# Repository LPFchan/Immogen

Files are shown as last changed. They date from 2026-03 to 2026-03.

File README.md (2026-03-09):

# Immogen — Ninebot G30 BLE Immobilizer

**Immogen** is a three-part BLE immobilizer system for the Ninebot Max G30, consisting of **[Uguisu](https://github.com/LPFchan/Immogen/tree/main/Uguisu#readme)** (key fob), **[Guillemot](https://github.com/LPFchan/Immogen/tree/main/Guillemot#readme)** (deck receiver), and **[Whimbrel](https://github.com/LPFchan/Whimbrel)** (Web Serial provisioning app).

Guillemot sits inline between the battery and ESC via an XT60 splice. Without a valid BLE unlock from Uguisu, the scooter stays inoperable. Male/female pigtails keep the install reversible—no permanent modification required.

```
┌─────────────────┐       BLE advertisement        ┌──────────────────────┐
│  UGUISU (FOB)   │ ─────────────────────────────> │ GUILLEMOT (RECEIVER) │
│  XIAO nRF52840  │       (2.4 GHz, ~2 m)          │  XIAO nRF52840       │
└───────┬─────────┘                                └──────────┬───────────┘
        │                                                     │
        │                 ┌────────────────────┐              │
        └──────(USB-C)──> │ WHIMBREL (WEB APP) │ <──(USB-C)───┘
       (Provisioning)     │ Chrome / Edge      │    (Provisioning)
                          └────────────────────┘
```

## Repository Structure

| Path | Description |
| --- | --- |
| `Uguisu/` | Key fob — firmware, KiCad, BOM. Button press → 2 s BLE broadcast → sleep. [README](https://github.com/LPFchan/Immogen/tree/main/Uguisu#readme) |
| `Guillemot/` | Deck receiver — firmware, KiCad, BOM. Duty-cycled scan (5%), validates adverts → SR latch → power gate. [README](https://github.com/LPFchan/Immogen/tree/main/Guillemot#readme) |
| `lib/` | Shared C++ library: AES-128-CCM MIC, provisioning loop, LittleFS counter storage |
| `tools/` | LED visualizer, BLE timing simulator, buzzer tuner (HTML); MIC test vectors (`gen_mic.py`) |
| `logs/` | Migration reports and guides |

## BLE Protocol

Advertisement-only; no persistent connection. Both devices share a company ID and pre-shared key (PSK). Each advertisement carries a 13-byte payload after the 2-byte company ID:

| Offset | Size | Field | Purpose |
| --- | ---- | --- | --- |
| 0 | 4 | counter | Anti-replay, monotonic |
| 4 | 1 | command | 0x01 = Unlock, 0x02 = Lock |
| 5 | 8 | mic | AES-128-CCM auth tag |

For full protocol details see the [Guillemot](https://github.com/LPFchan/Immogen/tree/main/Guillemot#readme) and [Uguisu](https://github.com/LPFchan/Immogen/tree/main/Uguisu#readme) READMEs.

## Quick Start

Pre-built firmware is available on the [Releases](https://github.com/LPFchan/Immogen/releases) page. Use [Whimbrel](https://github.com/LPFchan/Whimbrel) to flash and provision keys via Web Serial.

**Build from source:**

```bash
# Deck receiver
cd Guillemot/firmware && pio run

# Key fob
cd Uguisu/firmware && pio run
```

## Roadmap

- Uguisu enclosure CAD (3D print).
- First-build validation: PPK2 power, BLE range through deck, pre-charge waveform.

## Safety & Legal

- Prototype security/power-interrupt device. Use at your own risk.
- Not affiliated with Segway-Ninebot.
- **Do not test lock behavior while riding.**

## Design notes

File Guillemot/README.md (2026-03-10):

# Guillemot — Ninebot G30 BLE Immobilizer Receiver

Guillemot is the deck receiver in a three-part immobilizer system ([Uguisu](https://github.com/LPFchan/Immogen/tree/main/Uguisu) fob + [Whimbrel](https://github.com/LPFchan/Whimbrel) web app) for the Ninebot Max G30. It validates encrypted BLE advertisements from the fob and controls an SR latch that gates battery-to-ESC power via an inline XT60 splice. Male/female pigtails make it fully reversible—no permanent modification to the vehicle. Protocol and cryptography are handled by the shared [lib/](https://github.com/LPFchan/Immogen/tree/main/lib) in this monorepo ([Immogen](https://github.com/LPFchan/Immogen)).

---

## Hardware

### Placement

Mount Guillemot on the plastic underside of the deck for good 2.4 GHz RF.

### Components & BOM (~$20)

| Ref | Part | Notes | JLCPCB # | Cost |
| --- | --- | --- | --- | --- |
| U1 | XIAO nRF52840 | MCU: BLE scanning, latch control, buzzer PWM | Seeed | $8.23  |
| U2 | SN74LVC2G02DCTR | SR latch: Q = unlock. 10 nF + 100 kΩ differentiator for POR pulse | C94600 (ext.) | $0.53  |
| PS1 | TPSM365R6V3RDNR | Buck: 3–65 V in, 3.3 V/600 mA, 4 μA Iq. Feeds XIAO 3V3 directly.  | C18208843 (ext.) | $3.59  |
| Q1 | IPB042N10N3G | Main MOSFET: 100 V/137 A, D2PAK, low-side GND return | C69300 (ext.) | $0.75  |
| Q2 | AO3422 | Pre-charge FET, inrush ~0.8 A. Driven by latch Q. | C37130 (ext.) | $0.23  |
| Q3 | SI2309CDS | Bleeder P-FET: disconnects 10 kΩ bleeder when locked (0 μA) | C10493 (ext.) | $0.23  |
| Q4 | 2N7002 | Gate drive | C8545 | $0.01  |
| Q5, Q6 | MMBT3904 | Buzzer driver | C20526 | $0.02  |
| BZ1 | FUET-1230 | Buzzer: 12×12×3 mm SMD, 4 kHz. Driven by MMBT3904 | C391037 (ext.) | $0.47  |
| D1 | BZT52C12-7-F | 12 V Zener | C124196 (ext.) | $0.11  |
| D2 | BZT52C10-7-F | 10 V Zener | C155227 (ext.) | $0.10  |
| D3, D4 | 1N4148W | Gate isolation from buzzer rail sag | C81598 | $0.01  |
| D5 | SMBJ45A | 45 V TVS diode for transient suppression | C114005 (ext.) | $0.08  |
| C1 | 10 nF (0603) | POR pulse differentiator | C57112 | $0.003 |
| C2 | 100 µF (1210) | Bulk decoupling. EMK325ABJ107MM-P 16V X5R ±20% | C90143 (ext.) | $0.31  |
| C3, C4 | 1 µF (0603) | RC delay bypass, gate isolation | C15849 | $0.01  |
| R1, R2 | 100 kΩ (0603) | Latch input pull-downs (prevent floating during WDT reset) | C25803 | $0.006 |
| R3, R7 | 100 kΩ (0603) | Gate drive, RC delay (τ = 100 ms) | C25803 | $0.006 |
| R4 | 1 MΩ (0603) | P-FET gate pull-up | C22935 | $0.001 |
| R5 | 10 kΩ (0603) | Bleeder resistor | C25804 | $0.001 |
| R6 | 4.7 kΩ (0603) | Piezo buzzer discharge resistor | C23162 | $0.001 |
| R8 | 47 Ω 2 W (2512) | Pre-charge resistor, inrush ~0.77–0.89 A | C136992 (ext.) | $0.10  |
| TP1–5 | XT60 + 12 AWG | Pigtails and GND jumper | Generic | — |
| — | PCB | 54×34 mm, 2 oz outer | JLCPCB | $1.60  |

JLCPCB P&P for SMT. Hand-solder XIAO edges, XT60 pigtails, and the GND jumper.

### PCB Layout

4-layer, 54×34 mm, 2 oz outer copper, designed for 30 A continuous.

- **12 AWG GND jumper (critical):** Main battery return bypasses inner layers. Run an external silicone wire from the `BAT-` XT60 pad to the MOSFET source pad.
- **Power traces:** `+BATT` and `ESC-` as top-layer pours. No high-current vias.
- **Clearance:** ≥ 0.6 mm between 42 V power and 3.3 V logic.
- **Pre-charge trace:** Q2 → R8 → `ESC-` routed at **1.0 mm** to survive initial ~40 W inrush surge.
- **RF keepout:** Strip copper on all layers under the XIAO's BLE antenna trace.
- **Assembly:** Single-sided (F.Cu) SMT for easy JLCPCB PCBA.

### Operation

- **Unlock flow:** Uguisu advert → MCU validates → SET latch → Q HIGH → pre-charge 100 ms → MOSFET ON → buzzer tone.
- **Lock flow:** Uguisu advert → MCU validates → buzzer tone → RESET latch → Q LOW → P-FET OFF, pre-charge OFF → MOSFET OFF.
- **Power (locked):** ~306 μA (buck Iq + 5% duty-cycled scan + latch). At 306 μA, a G30 (15.3 Ah) would theoretically take ~5.7 years to drain; battery self-discharge (~12 months) dominates in practice. See `logs/15-BLE_POWER_ANALYSIS_AND_DOCUMENTATION_DISCREPANCY.md` for derivation.
- **Buzzer timing:** Unlock tone ~34 ms after 10 V rail up; lock tone before RESET.

### Design Notes

- **EasyEDA → KiCad:** Schematics and PCBs are designed in KiCad. [easyeda2kicad](https://github.com/wokwi/easyeda2kicad) is used to import symbols and footprints from EasyEDA/LCSC. Example: `easyeda2kicad --full --lcsc_id=Cxxxx` (replace `Cxxxx` with the LCSC part number).
- **Latch Input Pull-downs (100 kΩ):** R1 and R2 hold `MCU_D0` (SET) and `MCU_D1` (RESET) strictly LOW. This is critical because the nRF52840's pins float (high-impedance) during the 8-second hardware Watchdog Timer (WDT) reset cycle. Without these resistors, noise or capacitive coupling could randomly toggle the latch and power state while the MCU reboots.
- **AO3422:** 55 V Vds provides margin over the 42 V bus when locked.
- **Gate drive R (100 kΩ):** Protects the 2N7002 and BZT Zeners.
- **POR circuit (10 nF + 100 kΩ):** 1 ms RC differentiator—brief pulse zeros the latch at power-on.
- **RC delay (100 kΩ + 1 μF):** 1N4148W bypass for fast turn-off.
- **Gate isolation (1N4148W + cap):** Buzzer draw exceeds bleeder supply; diode and 1 μF hold cap prevent gate sag during tones (Vgs ≈ 9.3 V).
- **Gate pull-down (MMBT3904):** Via Q̄/RC, discharges hold cap for instant OFF.
- **IPB042N10N3G:** Outperforms TO-220 standing upright in sealed deck enclosures when thermal pad is stitched to B.Cu. **IPB035N10NF2S (3.5 mΩ)** is the long-term successor depending on LCSC stock.

---

## Software

### Firmware

[PlatformIO](https://platformio.org/) project in `firmware/`

Scanning is duty-cycled (25 ms every 500 ms, 5% duty) for reliable detection. P(detect) = 100% per button press because `scanWindow (25 ms) ≥ advInterval (20 ms)` guarantees full phase coverage. The receiver rejects any payload with an invalid AES-CCM MIC or a counter less than or equal to the last seen value (anti-replay). The receiver is also protected against MCU hangs by an 8-second hardware Watchdog Timer (WDT) which triggers a clean reboot without disrupting the latch state.

### Protocol

Validation and crypto via shared [lib/](https://github.com/LPFchan/Immogen/tree/main/lib). See [Immogen README § BLE Protocol](https://github.com/LPFchan/Immogen#ble-protocol) for full specification.

### Onboarding

Use [Whimbrel](https://github.com/LPFchan/Whimbrel) for both tasks:

- **Firmware flashing:** Web-based flasher via Web Serial. Enter bootloader mode with a double-tap on reset.
- **Key provisioning:** Connect via USB; Whimbrel injects the shared AES-128 key. Physical presence is required. The firmware has no serial commands to read the key back.

---

## Safety & Notes

- Prototype security and power-interrupt device. Use at your own risk.
- Do not test lock behavior while riding.
- Not affiliated with Segway-Ninebot.
- Avoid committing KiCad per-user state (`*.kicad_prl`) or lock files.

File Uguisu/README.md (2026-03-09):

# Uguisu — Ninebot G30 BLE Immobilizer Fob

Uguisu is the BLE key fob in a three-part immobilizer system ([Guillemot](https://github.com/LPFchan/Immogen/tree/main/Guillemot) receiver + [Whimbrel](https://github.com/LPFchan/Whimbrel) web app) for the Ninebot Max G30. It broadcasts short, encrypted BLE advertisements on button press to unlock or lock the vehicle. This repository contains the fob firmware and hardware design files. Protocol and cryptography via the shared [lib/](https://github.com/LPFchan/Immogen/tree/main/lib) in this monorepo ([Immogen](https://github.com/LPFchan/Immogen)).

---

## Hardware

### Components & BOM (~$10)

| Ref | Part | Notes | Source / LCSC | Cost  |
| --- | --- | --- | --- | ----- |
| U1 | XIAO nRF52840 | Castellated, 21×17.5 mm | Seeed/Amazon  | $6.00 |
| BAT | TW-502535 | 3.7V 400mAh LiPo | Generic | $2.00 |
| KEY1 | SKQGABE010 | Tactile Switch SMD-4P 5.2x5.2mm | C115351 | $0.11 |
| LED1 | XL-5050RGBC | SMD5050-6P RGB LED Common Anode | C2843868 | $0.05 |
| R1, R3 | 120 Ω | 0603WAF1200T5E, 100mW 1% (Blue/Green) | C22787 | <$0.01|
| R2 | 330 Ω | 0603WAF3300T5E, 100mW 1% (Red) | C23138 | <$0.01|
| — | Enclosure | ~50×35×12 mm, 3D-printed | Homemade | — |

Hand-solder XIAO and LiPo.

### PCB Design

KiCad (`hardware/Uguisu.kicad_sch` / `hardware/Uguisu.kicad_pcb`).

### GPIO

| Function | Pin | nRF P0.x | Notes |
| --- | --- | --- | --- |
| Button (KEY1) | D0  | P0.02 | Active-low, internal pull-up, wake-from-system-off |
| Blue (LED1) | D1  | P0.03 | LED1 pin 1, R1 120 Ω, active-low (sink) |
| Red (LED1) | D2  | P0.28 | LED1 pin 2, R2 330 Ω, active-low (sink) |
| Green (LED1)  | D3  | P0.29 | LED1 pin 3, R3 120 Ω, active-low (sink) |

### RGB LED Behaviour

| Situation | Color  | Pattern |
| --- | --- | --- |
| Unlock | Green  | Single pulse (fade-in/hold/fade-out) |
| Lock | Red | Single pulse (fade-in/hold/fade-out) |
| Serial provisioning | Blue | Repeating pulse loop |
| Low battery + Unlock | Green  | Rapid pulse loop for 2 s |
| Low battery + Lock | Red | Rapid pulse loop for 2 s |
| Fatal error (FS fail)  | Red | Fast blink + onboard LED |

All timing constants live in `firmware/include/led_effects.h`. Use `tools/led_visualizer.html` (repo root; open in any browser) to preview and fine-tune durations before flashing.

### Operation

- **Unlock flow:** Short press (< 1 s) → green flash → BLE broadcast ~2 s → sleep.
- **Lock flow:** Long press (≥ 1 s) → red flash → BLE broadcast ~2 s → sleep.
- **Low battery:** Battery checked after button press; replaces single flash with 2 s pulse loop in the same color while advertising.
- **Power:** ~30 μA standby (nRF52840 system-off + XIAO charging IC), ~0.006 mAh per press (12–18 months between charges on 400 mAh LiPo). Charging via USB-C.

### Design Notes

- **EasyEDA → KiCad:** Schematics and PCBs are designed in KiCad. [easyeda2kicad](https://github.com/wokwi/easyeda2kicad) is used to import symbols and footprints from EasyEDA/LCSC. Example: `easyeda2kicad --full --lcsc_id=Cxxxx` (replace `Cxxxx` with the LCSC part number).
- **NVS wear:** Counter written every press (System OFF kills RAM). At 10 unlocks/day, ~2.7 years; wear-leveling extends this.

---

## Software

### Firmware

[PlatformIO](https://platformio.org/) project in `firmware/`.

**Boot flow:**

```
led::init()
g_store.begin()          — fail → error_loop() [red rapid blink + onboard LED, forever]
load_provisioning()

VBUS present?
  yes → prov_led_task (blue pulse, FreeRTOS)
        ensure_provisioned()   [waits for PROV: serial packet]
        stop prov_led_task
        led::off()

Bluefruit.begin() / setName / setTxPower

wait_for_button_press_release(10 s)
  timeout → system_off()

command = press ≥ 1 s ? Lock : Unlock
cmd_pin = Lock ? PIN_LED_R : PIN_LED_G
low_bat = readVbat_mv() < LED_LOWBAT_MV_THRESHOLD

[crypto: nonce → msg → AES-128-CCM MIC]
  fail → system_off()

g_store.update(counter)
start_advertising_once()     — BLE advertising starts
adv_start = millis()

low_bat?
  yes → flash_low_battery(cmd_pin)   [~2 s repeating pulses, same color as command]
  no  → flash_once(cmd_pin, ...)     [~750 ms single pulse]

delay(UGUISU_ADVERTISE_MS - elapsed)   — wait out rest of advertising window

system_off()
```

Next press wakes via GPIO (hardware SENSE on `UGUISU_PIN_BUTTON_NRF`).

### Protocol

Generation and crypto via shared [lib/](https://github.com/LPFchan/Immogen/tree/main/lib). See [Immogen README § BLE Protocol](https://github.com/LPFchan/Immogen#ble-protocol) for full specification.

### Onboarding

Use [Whimbrel](https://github.com/LPFchan/Whimbrel) for both tasks:

- **Firmware flashing:** Web-based flasher via Web Serial. Enter bootloader mode with a double-tap on reset.
- **Key provisioning:** Connect via USB; Whimbrel injects the shared AES-128 key. Physical presence is required. The firmware has no serial commands to read the key back.

---

## Safety & Notes

- Prototype security device. Use at your own risk.
- Do not test lock behavior while riding.
- Not affiliated with Segway-Ninebot.
- Avoid committing KiCad per-user state (`*.kicad_prl`) or lock files.

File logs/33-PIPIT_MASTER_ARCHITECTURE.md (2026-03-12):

# Pipit Master Architecture (Phase 1)

*Date: 2026-03-10*

**Status:** Finalized Master Architecture
**Scope:** Complete architectural blueprint for the Pipit companion app, Guillemot firmware integration, Whimbrel dashboard, and the BLE security protocol. This document serves as the single source of truth, superseding logs 30, 31, and 32.

---

## 1. Overview & Tech Stack

**Pipit** is the companion app for the Immogen immobilizer ecosystem. *(Note on Terminology: Throughout this document, the target Ninebot G30 or any future compatible PEV is referred to universally as the **vehicle**, not "scooter").* 

It provides:
1. **Proximity Unlock (Background):** Low-power background BLE service that detects the vehicle and automatically unlocks Guillemot based on RSSI thresholding.
2. **Active Key Fob (Foreground):** Manual lock/unlock UI, functionally identical to the Uguisu hardware fob.

**Tech Stack:**
* **Kotlin Multiplatform (KMP):** Shared business logic (AES-CCM crypto, state management). Ported from the existing C++ `immo_crypto` logic to pure Kotlin and validated against existing test vectors.
* **Native UI:** **UIKit** (iOS) and **Jetpack Compose** (Android). Native toolkits are used to ensure reliable integration with OS-level BLE background modes, camera (QR scanning), and secure keystores.

---

## 2. Key Slot Architecture

Guillemot supports **4 key slots** (0–3), each with an independent 16-byte AES-CCM PSK, monotonic counter, and an optional 24-character human-readable device name (e.g., "Jamie's iPhone"). Slots are divided into three **access tiers** based on slot number:

| Slot | Tier | Default Name | Description |
|---|---|---|---|
| **0** | Hardware | `Uguisu` | Reserved for the Uguisu hardware fob. Lock/unlock only. No BLE management. USB-only administration. |
| **1** | Owner | *(set during onboarding)* | The primary phone. Full management access via SMP. Enforced as the first phone provisioned from Whimbrel. |
| **2** | Guest | `Guest 1` | Lock/unlock + restricted management. No PIN knowledge required. |
| **3** | Guest | `Guest 2` | Lock/unlock + restricted management. No PIN knowledge required. |

The tier is implicit from the slot number — no additional flags or metadata are stored. See Section 5.5 for the access control enforcement model.

*Why independent slots?* Sharing a single symmetric key across multiple active devices breaks the monotonic counter system, causing "Leapfrog Desyncs" where the phones continuously reject each other's payloads. Independent slots completely eliminate counter desyncs.

---

## 3. BLE Proximity Architecture

### 3.1 Flipped Roles & iBeacon Wake
Because iOS background advertising is broken (CoreBluetooth strips Manufacturer Data and hashes Service UUIDs into a proprietary format), the BLE roles are flipped from the Uguisu model:
* **Guillemot (Advertiser):** Broadcasts a continuous beacon as a connectable GATT peripheral. The advertising interval dynamically shifts based on the latch state (see Section 3.2).
* **Pipit (Scanner):** Registers a background scanner filtering for the Immogen Proximity UUID.

**iOS Background Optimization:** CoreBluetooth background scanning is throttled to ~3–4 minute intervals, which is unacceptable for proximity unlock. To mitigate this, Guillemot simultaneously broadcasts an **iBeacon** advertisement using a dedicated Immogen Proximity UUID (`66962B67-9C59-4D83-9101-AC0C9CCA2B12`). The iBeacon broadcasts at a **fixed 300 ms interval**, independent of the latch state. This interval aligns perfectly with Apple's CoreLocation specifications, reliably waking Pipit via a hardware-level path within ~1–2 seconds of approach. The nRF52840's extended advertising support allows both iBeacon and GATT advertisements to broadcast concurrently without alternation.

*   **iOS flow:** CoreLocation detects iBeacon region entry → wakes Pipit → Pipit initiates CoreBluetooth GATT connection → evaluates RSSI → sends payload.
*   **Android flow:** Foreground Service scans directly for the GATT advertisement (no iBeacon needed; Android background scanning is unrestricted).

**iOS Permission Requirement:** iBeacon region monitoring requires **"Always Allow" location permission**. Pipit must request this during onboarding. Users who decline are degraded to the slow CoreBluetooth background scanning path (~3–4 minute intervals). This trade-off should be communicated clearly in the permission prompt.

### 3.2 Stateful Proximity Beaconing & Dynamic Intervals
To support both "approach-to-unlock" and highly-responsive "walk-away-to-lock" without causing severe battery drain on the phone while riding, Guillemot dynamically changes both its advertised Service UUID and its **GATT advertising interval** based on the latch state:

| State Beacon | UUID | Interval | Purpose |
|---|---|---|---|
| **Immogen Proximity - Locked** | `C5380EF2-C3FC-4F2A-B3CC-D51A08EF5FA9` | **300 ms** | Balances battery conservation while parked with relatively fast discovery during approach. |
| **Immogen Proximity - Unlocked** | `A1AA4F79-B490-44D2-A7E1-8A03422243A1` | **200 ms** | Provides high-fidelity, high-frequency RSSI data to the phone to accurately detect walk-aways. |

*   **Approach (When Locked):** Guillemot advertises the Locked UUID at 300 ms. Pipit lazily scans for this UUID. When detected, Pipit evaluates the RSSI against the unlock proximity threshold. If strong enough, it connects via GATT and sends the Unlock payload.
*   **Walk-Away (When Unlocked):** Guillemot switches to the Unlocked UUID at 200 ms. Pipit monitors the Unlocked UUID, maintaining a rolling history of the high-frequency RSSI readings. 
    * **Normal Walk-Away:** When the RSSI drops below the lock proximity threshold (-75 dBm), Pipit connects and sends the Lock payload.
    * **Abrupt Dropout Edge Case:** If the beacon drops entirely *before* reaching the threshold (e.g., walking behind a concrete wall), Pipit analyzes the recent RSSI history. If the trend was decreasing, Pipit infers a walk-away and enters an aggressive scanning state, firing the Lock payload the instant the beacon is visible again. If the trend was stable (e.g., phone reboots mid-ride), it assumes a sudden failure and safely ignores the drop.

### 3.3 RSSI Thresholds & Hysteresis
To prevent rapid lock/unlock cycling when the user hovers near the proximity boundary, the unlock and lock thresholds are separated by a 10 dBm hysteresis gap:
*   **Unlock threshold (default):** **-65 dBm** — phone must be close (~1–2 meters) to trigger unlock.
*   **Lock threshold (default):** **-75 dBm** — phone must move significantly farther away (~4–5 meters) before re-locking.

Both thresholds are user-configurable in Pipit's settings. The 10 dBm gap ensures that once unlocked, minor RSSI fluctuations from body movement, pocket placement, or multipath reflections do not trigger spurious re-locks.

---

## 4. GATT & Payload Protocols

### 4.1 GATT Service & Characteristic UUIDs

| Component | UUID |
|---|---|
| **Immogen Proximity Service** | `942C7A1E-362E-4676-A22F-39130FAF2272` |
| Unlock/Lock Command Characteristic | `2522DA08-9E21-47DB-A834-22B7267E178B` |
| Management Command Characteristic | `438C5641-3825-40BE-80A8-97BC261E0EE9` |
| Management Response Characteristic | `DA43E428-803C-401B-9915-4C1529F453B1` |

### 4.2 GATT Characteristic Structure
Guillemot's `Immogen Proximity` GATT service exposes three characteristics:

1.  **Unlock/Lock Command (Write Without Response):** Receives the 14-byte encrypted AES-CCM payload. Like the Uguisu hardware fob, this is a "fire-and-forget" blind write. No custom GATT error feedback is required.
2.  **Management Command (Write, Authenticated Link):** Gated by the 6-digit BLE Pairing PIN. Receives administrative commands (e.g., `PROV`, `REVOKE`, `RENAME`, `SLOTS?`).
3.  **Management Response (Notify):** Returns asynchronous responses to management commands. All responses are structured JSON (see Section 6).

**MTU Negotiation:** The `SLOTS?` Management Response returns a JSON array containing all 4 slots, which can easily exceed 150 bytes. To accommodate this in a single BLE Notification without fragmentation, Guillemot requests an MTU exchange to **247 bytes** (the nRF52 maximum) upon connection. Note that Web Bluetooth handles MTU negotiation automatically based on the peripheral's request, so Whimbrel does not need an explicit MTU API call.

### 4.3 Payload Structure & Slot Identification
The 14-byte command payload structure is: `[1-byte Prefix (AAD)] [4-byte Counter (AAD)] [1-byte Command (Ciphertext)] [8-byte MIC]`.

The 1-byte Prefix carries only the Slot ID to route payloads to the correct AES key without brute-forcing decryption across all slots. The Command remains encrypted in the ciphertext to preserve confidentiality.
*   **`Prefix = (Slot_ID << 4)`**
*   **Upper 4 bits:** Target Key Slot (0-3).
*   **Lower 4 bits:** Reserved (zero).

*Example:* `0x10` instructs Guillemot to pull the AES key for Slot 1. The actual command (Unlock/Lock) is only revealed after successful AES-CCM decryption.

---

## 5. Security & Management PIN

### 5.1 The 6-Digit Management PIN
A 6-digit PIN is established during the initial USB-C setup. This PIN serves two roles:
1. **BLE Pairing PIN (SMP):** Used as the standard BLE Pairing PIN for authenticated management sessions.
2. **QR Key Encryption:** Used as the input to an Argon2id KDF to derive an AES-128 key that encrypts the slot key inside provisioning QR codes (see Section 7.1).

### 5.2 Security via BLE Pairing PIN (SMP)
The PIN is not sent as a custom plaintext payload. It acts as the **standard BLE Pairing PIN (SMP)**. When Pipit or Whimbrel attempts to access Management characteristics, the host OS (iOS/Android/Windows) natively prompts the user for the 6-digit PIN. This establishes a fully encrypted and MITM-protected BLE session before any sensitive data (like new AES root keys) is transmitted.

*Because the SoftDevice requires the plaintext PIN to execute the SMP mathematical handshake, the `SETPIN` command transmits and stores the 6 digits in plaintext.*

### 5.3 Brute-Force Rate Limiting & DoS Mitigation
* Exponential backoff after 3 consecutive failures (5s → 10s → 20s → 40s → ...).
* **Temporary Lockout:** After 10 consecutive failures, BLE management characteristics are disabled entirely for **1 hour**.
* **Anti-DoS Reset Bypass:** Receiving *any* valid, successfully authenticated AES-CCM Lock or Unlock payload (via the Write Without Response characteristic) proves physical key ownership and **instantly resets the PIN failure counter to zero**, clearing the lockout. This ensures a malicious actor cannot permanently deny the owner BLE management access by spamming bad PINs.

### 5.4 Counter Security Model
Each key slot maintains an independent strictly-monotonic counter. Guillemot rejects any payload where `counter <= last_seen_counter` for that slot. There is no tolerance window — this is by design. A single replayed or out-of-order payload is always rejected. This strict model is the core of the anti-replay security and eliminates the complexity of window-based counter acceptance.

### 5.5 Slot-Based Access Tiers & the `IDENTIFY` Command

Management access is gated by two layers: **SMP authentication** (the phone knows the 6-digit PIN) and **slot identity** (the phone proves which slot it owns). SMP gets you through the door; `IDENTIFY` determines what you can do inside.

**The `IDENTIFY` command:**
At the start of any management session, the phone sends an `IDENTIFY` payload — a standard 14-byte AES-CCM packet (same format as lock/unlock, Section 4.3) with command byte `0x03`. The prefix byte carries the claimed slot ID. Guillemot decrypts the payload using the claimed slot's key:
*   **MIC valid + counter valid →** Session is bound to that slot. Guillemot stores a `session_slot` variable for the lifetime of the GATT connection.
*   **MIC invalid →** Rejected. The session remains unbound and all subsequent management commands are refused.

The `IDENTIFY` payload uses the same counter as lock/unlock (incrementing the slot's monotonic counter). This is acceptable — one counter tick per management session is negligible.

**Unidentified sessions:** If a phone pairs via SMP but never sends `IDENTIFY` (or sends an invalid one), Guillemot refuses all management commands except `SLOTS?` (read-only, no harm). This means a guest phone that only knows the PIN but has no slot key gets no write access even if it manages to pair.

**Permission matrix (enforced in Guillemot's parser after `IDENTIFY`):**

| Command | Slot 1 (Owner) | Slot 2–3 (Guest) | No IDENTIFY (e.g. Lost Phone) |
|---|---|---|---|
| `IDENTIFY` | ✓ | ✓ | N/A |
| `SLOTS?` | ✓ | ✓ | ✓ (read-only fallback) |
| `PROV:<any>` | ✓ | ✗ | ✗ |
| `REVOKE:<any>` | ✓ | ✗ | ✗ |
| `RENAME:<own slot>` | ✓ | ✗ | ✗ |
| `RENAME:<other slot>` | ✓ | ✗ | ✗ |
| `RECOVER:<slot>` | ✗ | ✗ | ✓ *(Only if vehicle is UNLOCKED)* |
| `SETPIN` | serial-only | serial-only | serial-only |
| `RESETLOCK` | serial-only | serial-only | serial-only |

*(Note: The `RECOVER` command allows an unidentified phone to replace a key, but Guillemot strictly enforces that the vehicle's hardware latch must be HIGH/Unlocked for it to succeed. See Section 7.3).*

**Guest access in practice:** Guest phones (Slot 2–3) provision via **unencrypted QR codes** (Section 7.1.1) and never learn the management PIN. They interact exclusively with the Unlock/Lock Command characteristic (Write Without Response, no SMP required). Guests have zero management write access, even to their own slot names.

**Why not skip `IDENTIFY` and just use SMP bonds?** SMP bonds (LTK + IRK) are device-level — they prove "this phone paired before" but not "this phone owns Slot N." IRKs also break when the user clears Bluetooth data, re-pairs, or switches phones. The `IDENTIFY` command provides cryptographic proof of slot ownership that survives re-pairing and is unforgeable without the slot key.

---

## 6. Serial & Management Protocol

### 6.1 Command Transport
Commands are accepted over two transports with different permission levels:

| Command | USB-C Serial | BLE GATT (Authenticated) | Tier Gate |
|---|---|---|---|
| `IDENTIFY` (14-byte AES-CCM payload) | N/A | Yes | Any slot |
| `PROV:<slot>:<key>:<ctr>:[name]` | Yes | Yes | Owner only |
| `RENAME:<slot>:<name>` | Yes | Yes | Owner only |
| `SLOTS?` | Yes | Yes | Any (incl. unidentified) |
| `REVOKE:<slot>` | Yes | Yes | Owner only |
| `RECOVER:<slot>:<key>:<ctr>:[name]` | Yes | Yes | Unidentified (requires Unlocked vehicle) |
| `SETPIN:<6digits>` | Yes | **No** (serial-only) | N/A |
| `RESETLOCK` | Yes | **No** (serial-only) | N/A |

`IDENTIFY` is sent as a 14-byte AES-CCM payload (same format as lock/unlock, command byte `0x03`) through the Management Command characteristic. It binds the BLE session to a slot and access tier (see Section 5.5). Must be sent before any standard write commands; only `SLOTS?` and `RECOVER` are allowed without identification.

`SETPIN` and `RESETLOCK` are restricted to USB-C serial because they are recovery/bootstrap operations. Exposing `RESETLOCK` over BLE would allow an attacker to clear brute-force lockout and keep attacking the PIN. `SETPIN` is serial-only to prevent remote PIN changes by a compromised phone.

### 6.2 Response Format
All management commands respond with structured JSON over both transports:

**Success responses:**
```json
{"status":"ok","slot":1,"name":"iPhone","counter":0}
```

**Error responses:**
```json
{"status":"error","code":"MALFORMED","msg":"invalid slot"}
```

**`SLOTS?` response:**
```json
{"status":"ok","slots":[
  {"id":0,"used":true,"counter":4821,"name":"Uguisu"},
  {"id":1,"used":true,"counter":127,"name":"iPhone"},
  {"id":2,"used":false,"counter":0,"name":""},
  {"id":3,"used":false,"counter":0,"name":""}
]}
```

---

## 7. Key Provisioning, Migration, and Recovery

### 7.1 Initial Provisioning — Owner (Whimbrel)
1. Flash Guillemot and Uguisu via USB-C.
2. Whimbrel asks user to set the 6-digit PIN (`SETPIN:123456`).
3. Whimbrel provisions Slot 1 (`PROV:1:<key>:0:iPhone`).
4. Whimbrel generates an **encrypted QR code:**
   * Derives an AES-128 key from the PIN using **Argon2id** (parameters: `m=262144` (256 MB), `t=3`, `p=1`, with a random 16-byte salt).
   * Encrypts the slot key using AES-CCM with the derived key.
   * QR contains: `immogen://prov?slot=1&salt=<hex>&ekey=<encrypted_key_hex>&ctr=0&name=iPhone`
   * The PIN is **never** included in the QR code.
5. User scans the QR on their phone. Pipit prompts for the 6-digit PIN, derives the same AES key via Argon2id, decrypts the slot key, and stores it in the platform's secure keystore.

*Security: Even if the QR code is photographed, the slot key cannot be recovered without the 6-digit PIN. Argon2id (256 MB) makes offline brute-force expensive (~800ms per guess on CPU, ~220 hours for 1M combinations; ~12 hours on a 10-GPU cluster).*

### 7.1.1 Guest Provisioning (Whimbrel or Pipit)
Guest slots (2–3) use **unencrypted QR codes**. The slot key is transmitted in plaintext within the QR payload — no Argon2id, no PIN.

1. The owner provisions a guest slot via Whimbrel (`PROV:2:<key>:0:Guest 1`) or via Pipit (Section 10.6).
2. The provisioning device generates a **plaintext QR code:**
   * QR contains: `immogen://prov?slot=2&key=<hex>&ctr=0&name=Guest%201`
   * Note: `key` field (plaintext) instead of `salt` + `ekey` (encrypted). The presence of `key` vs `ekey` tells the scanning phone whether to prompt for a PIN.
3. The guest scans the QR. Pipit detects the plaintext format, **skips the PIN prompt entirely**, stores the slot key directly in the secure keystore, and completes onboarding.

*Security trade-off: If the QR is photographed or intercepted, the attacker obtains the slot key and can lock/unlock the vehicle. This is accepted for guest slots because (a) QR exchange typically happens in person, (b) the owner can revoke a guest slot at any time, and (c) guest slots have no management privileges. The owner's Slot 1 key is never exposed via this path.*

### 7.2 The "Migration" Flow (Happy Path)
Used when a user is upgrading to a new phone and has both devices in hand.
1. The old phone generates an **encrypted QR code** containing its current Slot ID, AES Key, and **current Counter value**, encrypted with the user's PIN via Argon2id (same scheme as Section 7.1).
2. The new phone scans the QR, prompts the user for their PIN, decrypts the credentials, and takes over the counter exactly where the old phone left off.
3. The old phone instantly deletes the key from its local secure storage.
*Result: Instant transfer, zero counter desyncs, no BLE management interaction required. QR is safe even if intercepted.*

### 7.3 The "Recovery" Flow (Break-Glass Path)
Used when a phone is lost or destroyed. The user only needs their 6-digit BLE Pairing PIN.
1. The user installs Pipit on a new phone, connects to Guillemot, and authenticates using the PIN.
2. Pipit queries the slots (`SLOTS?`), and Guillemot returns a JSON array.
3. Pipit displays a UI: *"Which device did you lose?"* listing the names (e.g., "Jamie's iPhone").
4. The user selects "Jamie's iPhone" (Slot 1).
5. Pipit issues `REVOKE:1`, instantly locking out the stolen phone.
6. Pipit generates a random 16-byte AES key using the platform's secure random generator (`SecRandomCopyBytes` on iOS, `SecureRandom` on Android) and provisions itself into that vacated slot via `PROV:1:<new_key>:0:New iPhone`.
*Result: Securely locks out the old device and establishes a brand new cryptographic counter baseline.*

---

## 8. Platform Capability Matrix

| Operation | Pipit (Android) | Pipit (iOS) | Whimbrel (laptop) |
|---|---|---|---|
| **Guillemot firmware flash** | USB OTG (`.uf2` via `libaums`) | Not supported | USB-C DFU |
| **Uguisu firmware/key flash** | USB OTG (CDC serial via `usb-serial-for-android`) | Not supported | Web Serial |
| **Key management (BLE)** | BLE GATT + OS PIN Prompt | BLE GATT + OS PIN Prompt | Web Bluetooth + OS PIN Prompt |
| **Phone provisioning** | Encrypted QR scan + PIN entry | Encrypted QR scan + PIN entry | Web Bluetooth + Encrypted QR display |
| **Proximity unlock** | Background scan (Foreground Service) | iBeacon region monitoring (CoreLocation) + GATT | N/A |
| **Active key fob** | BLE GATT write | BLE GATT write | N/A |

---

## 9. Required Codebase Modifications

Implementing this architecture requires targeted updates across all four projects in the monorepo:

### 9.1 `ImmoCommon` (Shared Library)
*   **Struct Update (`immo_storage.h`):** Refactor the storage struct from a single key/counter into an array of 4 Key Slots. Each slot must contain an AES key array, a monotonic counter, and a `char name[24]` buffer. A clean reflash is acceptable for the storage migration (prototyping phase).
*   **Crypto Update (`immo_crypto.cpp`):** Update `verify_payload()` to extract the `Slot ID` using bitwise logic (`prefix >> 4`), validate that the target slot is active, and fetch the correct AES key from storage before executing the CCM MIC check.

### 9.2 `Guillemot` (Immobilizer Firmware)
*   **BLE Initialization (`main.cpp`):** Initialize dual BLE roles (`Central` + `Peripheral`).
*   **Stateful Beaconing:** Implement advertising logic to dynamically swap the Service UUID between `Locked` and `Unlocked` based on the latch state.
*   **GATT Server Setup:** Define the `Immogen Proximity` service. Add the `Unlock Command` (Write Without Response), `Management Command` (Write), and `Management Response` (Notify) characteristics.
*   **Security Manager (SMP):** Configure the SoftDevice security manager to require an Authenticated Link for the Management characteristics. Feed the plaintext 6-digit PIN from flash into the `ble_gap_opt_passkey_t` structure.
*   **iBeacon Advertising:** Add a concurrent iBeacon advertising set using the Immogen Proximity UUID (`66962B67-9C59-4D83-9101-AC0C9CCA2B12`) via the nRF52840's extended advertising support.
*   **Parser Expansion:** Update the serial parser to handle the new `RENAME` command, accept names in the `PROV` command, format `SLOTS?` output as JSON, and accept 6 plaintext digits for `SETPIN`. Route incoming GATT `Management Command` writes into this same parser. The parser must gate `SETPIN` and `RESETLOCK` to serial-only; reject these commands when the source is GATT (see Section 6.1).

### 9.3 `Uguisu` (Hardware Fob Firmware)
*   **Prefix Byte Packing:** Update the payload builder in `Uguisu/firmware/src/main.cpp` to explicitly pack `0x00` (Slot 0) into the upper 4 bits of the prefix byte when broadcasting, ensuring Guillemot routes the payload to the reserved hardware fob slot.

### 9.4 `Whimbrel` (Web Dashboard)
*   **Protocol Updates (`serial.js` / `api.js`):** Update the API wrappers to append device names to the `PROV` command, implement the `RENAME` command, and send `SETPIN` as plaintext digits instead of a hash.
*   **BLE Management (`js/`):** Implement Web Bluetooth to connect to the new GATT service, request access to the `Management Command` characteristic (triggering the browser's native PIN prompt), and listen to `Management Response` notifications.
*   **JSON Parsing:** Parse the JSON response from `SLOTS?` to populate the dashboard UI with slot IDs, usage status, and device names.
*   **UI & QR Updates (`app.js` / `prov.js`):** Add text fields for Device Name during the "Add Phone" wizard. Add an "Edit Name" button next to active slots in the dashboard view. Implement Argon2id KDF + AES-CCM encryption for QR code generation. The QR payload must contain the salt, encrypted key, counter, slot, and name — but never the PIN. *(Note: Since the native WebCrypto API lacks Argon2id support, Whimbrel requires a WebAssembly port like `argon2-browser` to derive the QR encryption key).*

---

## 10. Pipit UI/UX Architecture

### 10.1 Navigation Model
Pipit uses a **single-screen utility model**. The Home screen (key fob) is always the root view. Settings is the only secondary surface — presented via a **3D flip transition** from the fob model (Section 10.4.2). All management flows (provisioning, migration, slot actions) are reached from within Settings. There are no tab bars, drawers, or deep navigation stacks.

**Theme:** System-follows (respects OS dark/light mode automatically).

### 10.2 Screen Inventory

```
┌──────────────────────────────────────────────────────────────────┐
│                        App Launch                                │
│                            │                                     │
│                 ┌──────────┴──────────┐                          │
│                 ▼                     ▼                          │
│       [No Key in Keystore]    [Key Exists in Keystore]           │
│                 │                     │                          │
│                 ▼                     ▼                          │
│         Onboarding Flow          Home Screen                     │
│         (Camera-first)               │                          │
│                 │              ⚙ flip transition                 │
│                 ▼                     ▼                          │
│            Home Screen           Settings                        │
│                                      ├── Proximity controls      │
│                                      ├── Key Slots (inline)      │
│                                      │    ├── ⋮ Rename           │
│                                      │    ├── ⋮ Replace ──▶ Replace Flow  │
│                                      │    ├── ⋮ Delete           │
│                                      │    └── ⊕ ──▶ Provision New Phone   │
│                                      ├── Transfer to New Phone   │
│                                      ├── USB Flashing (Android)  │
│                                      └── About                   │
└──────────────────────────────────────────────────────────────────┘
```

---

### 10.3 Onboarding Flow (First Launch Only)

Triggered when no AES key exists in the platform secure keystore. The camera opens **immediately** — no welcome preamble.

**Step 1 — QR Scan (Camera-First)**
```
┌─────────────────────────────┐
│                             │
│  ▓▓▓▓▓▓▓▓▓▓▓▓▓▓▓▓▓▓▓▓▓▓▓  │
│  ▓▓▓▓▓▓▓▓▓▓▓▓▓▓▓▓▓▓▓▓▓▓▓  │
│  ▓▓▓▓▓▓▓▓▓▓▓▓▓▓▓▓▓▓▓▓▓▓▓  │
│  ▓▓▓▓▓┌───────────┐▓▓▓▓▓▓  │
│  ▓▓▓▓▓│           │▓▓▓▓▓▓  │
│  ▓▓▓▓▓│  [camera] │▓▓▓▓▓▓  │
│  ▓▓▓▓▓│           │▓▓▓▓▓▓  │
│  ▓▓▓▓▓└───────────┘▓▓▓▓▓▓  │
│  ▓▓▓▓▓▓▓▓▓▓▓▓▓▓▓▓▓▓▓▓▓▓▓  │
│  ▓  Scan from Whimbrel    ▓  │
│  ▓▓▓▓▓▓▓▓▓▓▓▓▓▓▓▓▓▓▓▓▓▓▓  │
│  ▓▓▓▓▓▓▓▓▓▓▓▓▓▓▓▓▓▓▓▓▓▓▓  │
│                             │
│   recover key from lost phone >│
│                             │
└─────────────────────────────┘
```
*   The app launches directly into a **full-screen camera view** with a **darkened overlay** (semi-transparent black, ~70% opacity) covering the entire screen. A **rounded-rectangle transparent window** (QR-sized, centered) cuts through the overlay to form the viewfinder.
*   The instruction text *"Scan from Whimbrel"* sits inside the darkened overlay below the viewfinder.
*   **"recover key from lost phone >"** — a subtle text link at the bottom of the screen. Tapping it launches the Self-Provisioning Recovery Variant of the Replace Flow (Section 10.7).
*   Non-Immogen QR codes (anything not starting with `immogen://prov?`) are **silently ignored** — the viewfinder simply continues scanning. No error toast or inline message.
*   On valid scan → Pipit inspects the QR payload format:
    *   **Encrypted QR** (has `salt` + `ekey` fields — owner/migration): Proceeds to Step 2 (PIN Entry).
    *   **Plaintext QR** (has `key` field — guest provisioning, Section 7.1.1): **Skips PIN entry entirely.** Stores the slot key directly in the secure keystore and jumps straight to the QR Decryption Animation (Step 3, with no KDF wait).

**Step 2 — PIN Entry (Owner Only — Skipped for Guest QR)**
```
┌─────────────────────────────┐
│                             │
│   Enter your 6-digit PIN    │
│                             │
│   This is the PIN you set   │
│   during Guillemot setup.   │
│                             │
│     ┌─┐┌─┐┌─┐┌─┐┌─┐┌─┐    │
│     │ ││ ││ ││ ││ ││ │    │
│     └─┘└─┘└─┘└─┘└─┘└─┘    │
│                             │
│        [ Confirm ]          │
│                             │
└─────────────────────────────┘
```
*   Pipit derives the AES-128 key from the entered PIN via Argon2id (using the salt from the QR payload) and attempts decryption.
*   **Wrong PIN:** Inline error — *"Incorrect PIN. Please try again."* (client-side only; no brute-force concern since the QR is local data).
*   **Correct PIN →** triggers the QR Decryption Animation (Step 3).

**Step 3 — QR Decryption Animation**

On successful PIN entry, a **~1 second visual animation** plays before revealing the result. This mirrors the AES key creation visualization used in Whimbrel.

The animation sequence:
1.  **Dissolve (0–400 ms):** The QR code image (still on screen from Step 1, or re-shown as a thumbnail) breaks apart into a particle field — individual modules scatter outward with randomised velocities and slight rotation. The particles are small squares matching the QR module grid.
2.  **Convergence (400–800 ms):** The scattered particles re-converge toward the center, collapsing into a tight cluster. As they converge, their color shifts from neutral (black/white QR modules) to the app's accent color.
3.  **Resolve (800–1000 ms):** The particle cluster snaps into a key icon (or lock icon) with a brief glow/pulse, signaling "decryption complete". A short haptic fires at the resolve point (`.medium` impact).

The animation is purely decorative — the actual Argon2id KDF + AES-CCM decryption runs concurrently during steps 1–2 and completes well before the animation ends. If KDF takes longer than expected on older hardware, the animation pauses at the convergence phase and holds until decryption finishes.

**Step 4 — Location Permission (iOS Only)**
```
┌─────────────────────────────┐
│                             │
│   Enable proximity unlock?  │
│                             │
│   Pipit can automatically   │
│   unlock your vehicle when  │
│   you walk up to it.        │
│                             │
│   This requires "Always     │
│   Allow" location access    │
│   so the app can detect     │
│   your vehicle in the       │
│   background.               │
│                             │
│   Your location is never    │
│   stored or transmitted.    │
│                             │
│   [ Enable Proximity ]      │
│   [ Skip for Now ]          │
│                             │
└─────────────────────────────┘
```
*   **"Enable Proximity"** → triggers the iOS `CLLocationManager.requestAlwaysAuthorization()` system prompt. On Android, this step is skipped (background scanning uses a Foreground Service with no special location permission).
*   **"Skip for Now"** → proximity unlock is disabled; the user can enable it later from Settings. The app still functions as a manual key fob.

**Step 5 — Done (Slot Overview)**
```
┌─────────────────────────────┐
│                             │
│            ✓                │
│                             │
│   You're all set.           │
│                             │
│   Slot 0   Uguisu       🔑 │
│   Slot 1   Jamie's iPhone ● │
│            OWNER            │
│   Slot 2   — empty —       │
│            GUEST            │
│   Slot 3   — empty —       │
│            GUEST            │
│                             │
│        [ Done ]             │
│                             │
└─────────────────────────────┘
```
*   Shows all 4 slots (0–3) with their current state and tier labels (`OWNER` / `GUEST`). The user's own slot is highlighted with a dot or accent indicator. This gives the user a first look at the full slot topology and access hierarchy.
*   Dismisses the onboarding modal and reveals the Home screen.

---

### 10.4 Home Screen (Key Fob)

The primary and only persistent screen. Stripped down to the essential interaction: the **3D Uguisu model** and the **gear icon**. All status indicators, labels, and toggles have been removed to keep the screen maximally clean.

```
┌─────────────────────────────┐
│ ⚙                          │
│                             │
│                             │
│                             │
│   ╔═══════════════════════╗  │
│   ║                       ║  │
│   ║   [Uguisu 3D model]   ║  │
│   ║   perspective, lit    ║  │
│   ║   LED: off (idle)      ║  │
│   ║                       ║  │
│   ║                       ║  │
│   ╚═══════════════════════╝  │
│     Tap · Hold to lock      │
│                             │
│                             │
│                             │
└─────────────────────────────┘
```

**Layout Elements:**

1.  **Gear Icon (top-left):** Opens Settings via the 3D flip transition (Section 10.4.2).
2.  **3D Uguisu Model (center, dominant):** A real-time photorealistic render of the Uguisu fob. This is the only interactive element on the screen.

    **Gesture model (mirroring the physical fob):**
    *   **Short press (tap):** Sends the **Unlock** AES-CCM payload.
    *   **Long press (~700 ms hold):** Sends the **Lock** AES-CCM payload automatically the instant the 700 ms threshold is reached — no release required. A haptic fires at the same moment the packet is sent.

    **Visual states (matching real Uguisu fire-and-forget behaviour — LED flashes once per action, never holds):**
    *   **Idle (locked or unlocked):** Model rendered under neutral ambient lighting. The Uguisu's RGB LED is unlit (dark). There is no persistent visual difference between locked and unlocked — the model looks the same at rest regardless of latch state.
    *   **Unlock flash (on tap):** Model physically depresses (a subtle 1–2 mm push-in animation on the tactile button geometry). LED flashes green once (fade in 100 ms, hold 200 ms, fade out 200 ms), then returns to dark. Model button springs back.
    *   **Lock flash (on 700 ms threshold):** Model depresses briefly. LED flashes red once (same fade in/hold/fade out timing as unlock). Then returns to dark. Model button springs back.
    *   **Proximity auto-action:** When the background service triggers an auto-unlock or auto-lock, the model briefly plays the corresponding button-press + LED flash animation (without user touch) to communicate what happened.

    **Passive interactivity:**
    *   The model responds to device gyroscope input with a subtle parallax tilt (±5°), giving a sense of physical depth. This is purely cosmetic and can be disabled in Settings for users who find it distracting.

3.  **Hint Label:** Below the model, a small secondary text label: *"Tap · Hold to lock"* (visible until the user performs their first intentional lock, then hidden permanently via `UserDefaults` / `SharedPreferences` flag).

---

### 10.4.1 Disconnect Overlay

When Guillemot is not reachable, the home screen shows a **full-screen semi-transparent overlay** instead of dimming the model. The overlay follows the system theme:
*   **Light mode:** White overlay, ~60% opacity.
*   **Dark mode:** Black overlay, ~60% opacity.

The Uguisu 3D model remains faintly visible beneath the overlay but is **non-interactive** (touch events are consumed by the overlay).

```
┌─────────────────────────────┐
│ ⚙                          │
│▒▒▒▒▒▒▒▒▒▒▒▒▒▒▒▒▒▒▒▒▒▒▒▒▒▒▒│
│▒▒▒▒▒▒▒▒▒▒▒▒▒▒▒▒▒▒▒▒▒▒▒▒▒▒▒│
│▒▒▒▒▒▒▒▒▒▒▒▒▒▒▒▒▒▒▒▒▒▒▒▒▒▒▒│
│▒▒▒▒▒▒▒▒▒▒▒▒▒▒▒▒▒▒▒▒▒▒▒▒▒▒▒│
│▒▒▒▒▒ ○ Disconnected ▒▒▒▒▒▒▒│
│▒▒▒▒▒▒▒▒▒▒▒▒▒▒▒▒▒▒▒▒▒▒▒▒▒▒▒│
│▒▒▒▒▒▒▒▒▒▒▒▒▒▒▒▒▒▒▒▒▒▒▒▒▒▒▒│
│▒▒▒▒▒▒▒▒▒▒▒▒▒▒▒▒▒▒▒▒▒▒▒▒▒▒▒│
│▒▒▒▒▒▒▒▒▒▒▒▒▒▒▒▒▒▒▒▒▒▒▒▒▒▒▒│
└─────────────────────────────┘
```

**States:**
*   `○ Disconnected` — Default when beacon is not detected. Shown as a centered label with a gray dot. No pulsing, no animation — the user can see at a glance that the vehicle is out of range.
*   `✕ Bluetooth is off` — Shown when BLE is disabled system-wide. Tapping the label deep-links to the OS Bluetooth settings.

The overlay **fades out** (200 ms) as soon as the Guillemot beacon is detected and a GATT connection is established. The gear icon remains accessible above the overlay so the user can always reach Settings regardless of connection state.

---

### 10.4.2 Settings Transition (3D Flip)

Tapping the gear icon triggers a **3D flip animation** that transitions from the Home screen to the Settings view:

1.  **Flip (0–400 ms):** The Uguisu 3D model begins a 180° rotation around its vertical axis (Y-axis), as if the user is flipping the physical fob over to look at its back. The model simultaneously scales up slightly (~1.1×) to fill more of the screen.
2.  **Morph (400–600 ms):** As the model completes the flip and shows its "back", the back surface cross-fades into the Settings content pane. The rounded edges of the model's silhouette expand to become the Settings sheet's rounded corners.
3.  **Settle (600–700 ms):** The Settings pane is fully visible and interactive.

**Reverse transition (closing Settings):** Tapping the close button (✕) or swiping down plays the animation in reverse — the Settings pane compresses back into the model's silhouette, the model flips 180° back to its front face, and settles into the Home screen position.

The transition is implemented using the platform's native 3D transform APIs:
*   **iOS:** `CATransform3D` with perspective (`m34`) on a snapshot layer, cross-fading to the Settings `UIViewController`.
*   **Android:** `View.rotationY` with `cameraDistance` on a shared element transition between the Compose surfaces.

---

### 10.4.3 3D Model Asset & Rendering

**Model source:**
The 3D model is derived from the Uguisu enclosure CAD once it is finalized. The PCB footprint is known (~35 × 46 mm, r ~2 mm rounded corners) and the enclosure envelope is ~50 × 35 × 12 mm. Until the enclosure CAD is complete, a **development placeholder** — a rounded-rectangle slab at the correct dimensions with a visible PCB texture — is used so rendering infrastructure can be built and validated independently of enclosure design.

The final model must include:
*   The enclosure body with accurate surface finish (3D-printed texture or smooth depending on final print).
*   The tactile button (SKQGABE010, 5.2 × 5.2 mm) as a distinct depressible geometry.
*   The RGB LED (XL-5050RGBC, SMD5050) as a separate emissive mesh controlled at runtime.
*   USB-C port cutout on the appropriate edge.

**Asset formats:**
*   `.glb` (glTF Binary) — used by Android (Filament/SceneView).
*   `.usdz` — used by iOS (RealityKit). Converted from the master `.glb` via Apple's `Reality Converter` or `usdzconvert`.
*   Both formats are bundled in the app (not downloaded at runtime). Total combined size target: < 5 MB.

**Rendering stack (fully native — no KMP sharing possible):**

| Platform | Library | Notes |
|---|---|---|
| iOS | **RealityKit** (`ARView` in non-AR mode) | PBR materials, environment lighting, entity animation. Gyroscope via `CMMotionManager`. |
| Android | **SceneView** (Filament-based, maintained Sceneform successor) | PBR materials, IBL environment map. Gyroscope via `SensorManager`. |

**Lighting:** Both platforms use an Image-Based Lighting (IBL) environment map simulating an outdoor environment (overcast sky). This gives the plastic/metal surfaces on the model a realistic appearance without requiring dynamic scene lights.

**LED emissive control at runtime:**
The LED mesh has its emissive color and intensity driven by the app state machine — not baked into the asset. The LED is **off by default** and only fires during transient flash animations (matching Uguisu's fire-and-forget behaviour):
*   `idle` (locked or unlocked) → emissive intensity: 0.0 (off)
*   `unlock flash` → emissive color: `#00FF00`, intensity ramps 0→1.0→0 over 500 ms (fade in 100 ms, hold 200 ms, fade out 200 ms)
*   `lock flash` → emissive color: `#FF0000`, same intensity ramp as unlock

The LED mesh is named `led_rgb` in the glTF scene graph so both platform renderers can address it by name at load time.

---

### 10.4.4 Haptics & Sound

Every interaction with the Uguisu model produces both a haptic and an optional sound response. Sound playback is conditional on the device's silent mode — sound never plays if the user has silenced their device.

**Haptic schedule:**

| Event | iOS (`UIImpactFeedbackGenerator`) | Android (`HapticFeedbackConstants` / `VibrationEffect`) |
|---|---|---|
| **Short press registered (unlock)** | `.light` impact | `KEYBOARD_TAP` |
| **Long press fires at 700 ms (lock payload sent)** | `.heavy` impact | `HapticFeedbackConstants.CONFIRM` (API 30+) or 80 ms `VibrationEffect.createOneShot` |
| **Disconnect overlay tap (rejected)** | `UINotificationFeedbackGenerator` `.error` | `HapticFeedbackConstants.REJECT` (API 30+) or double-short `VibrationEffect` |
| **Proximity auto-action (background service)** | `.light` (fires when app is foregrounded and model animates) | Same |
| **QR decryption animation resolve** | `.medium` impact | `LONG_PRESS` |

The long press is a single haptic event at the 700 ms threshold — the moment the packet fires. There is no mid-hold tick because the action is already complete; the heavy impact *is* the confirmation.

**Sound design:**

Both sounds are short, low-frequency mechanical clicks recorded or synthesised to evoke a physical tactile switch — not a UI chime. They should feel like the SKQGABE010 button on the actual Uguisu hardware.

*   **Unlock click:** A crisp, bright click (~40 ms, fast attack, no tail). Analogous to a single button press.
*   **Lock clunk:** A slightly heavier, deeper click (~60 ms, marginally slower attack). The extra weight communicates "this is a more deliberate action" without being alarming.

**Silent mode handling:**

*   **iOS:** Audio is played via `AVAudioPlayer` with the session category set to `.ambient`. This category automatically respects the hardware silent switch — no explicit mute check required.
*   **Android:** Before playback, check `AudioManager.getRingerMode()`. Play only if the result is `RINGER_MODE_NORMAL`. In `RINGER_MODE_VIBRATE` or `RINGER_MODE_SILENT`, skip audio entirely (haptics still fire since vibration is not affected by ringer mode on most devices).

Sound assets are bundled in the app as short `.caf` (iOS) and `.ogg` (Android) files, targeting < 20 KB each.

---

### 10.5 Settings & Key Management

Revealed via the 3D flip transition from the Home screen (Section 10.4.2). Key management is **inline** — slot rows are embedded directly in the Settings view, not behind a separate screen. Accessing the KEYS section requires an active BLE management connection (authenticated via SMP PIN). If not already connected, Pipit initiates the connection and the OS prompts for the 6-digit PIN when the user scrolls to or interacts with the KEYS section.

```
┌─────────────────────────────┐
│  Settings                 ✕ │
│─────────────────────────────│
│                             │
│  PROXIMITY                  │
│  ┌─────────────────────────┐│
│  │ Background Unlock  [ON] ││
│  │─────────────────────────││
│  │ Unlock Distance   ━━●━━ ││
│  │ (~2m / -65 dBm)        ││
│  │─────────────────────────││
│  │ Lock Distance     ━●━━━ ││
│  │ (~5m / -75 dBm)        ││
│  └─────────────────────────┘│
│                             │
│  KEYS                       │
│  ┌─────────────────────────┐│
│  │ Slot 0  Uguisu     🔑 ⋮││  ← ⋮ on Android only
│  │─────────────────────────││
│  │ Slot 1  Jamie's iPhone ⋮││
│  │─────────────────────────││
│  │ Slot 2       ⊕          ││
│  │─────────────────────────││
│  │ Slot 3       ⊕          ││
│  └─────────────────────────┘│
│                             │
│  DEVICE                     │
│  ┌─────────────────────────┐│
│  │ Transfer to New Phone ▶ ││
│  │─────────────────────────││
│  │ Change PIN (USB)      ▶ ││  ← Android only
│  │─────────────────────────││
│  │ Flash Firmware (USB)  ▶ ││  ← Android only
│  └─────────────────────────┘│
│                             │
│  ABOUT                      │
│  ┌─────────────────────────┐│
│  │ Version            1.0  ││
│  └─────────────────────────┘│
│                             │
└─────────────────────────────┘
```

Pipit detects the current phone's slot tier at launch (from the stored slot ID) and renders the appropriate settings variant. The two layouts share the same flip transition and visual shell — only the content differs.

---

### 10.5.1 Owner Settings (Slot 1)

```
┌─────────────────────────────┐
│  Settings                 ✕ │
│─────────────────────────────│
│                             │
│  PROXIMITY                  │
│  ┌─────────────────────────┐│
│  │ Background Unlock  [ON] ││
│  │─────────────────────────││
│  │ Unlock Distance   ━━●━━ ││
│  │ (~2m / -65 dBm)        ││
│  │─────────────────────────││
│  │ Lock Distance     ━●━━━ ││
│  │ (~5m / -75 dBm)        ││
│  └─────────────────────────┘│
│                             │
│  KEYS                       │
│  ┌─────────────────────────┐│
│  │ Slot 0  Uguisu     🔑 ⋮││
│  │─────────────────────────││
│  │ Slot 1  Owner's iPhone  ││  ← own slot, no ⋮
│  │         OWNER           ││
│  │─────────────────────────││
│  │ Slot 2  Guest 1        ⋮││
│  │         GUEST           ││
│  │─────────────────────────││
│  │ Slot 3       ⊕          ││
│  │         GUEST           ││
│  └─────────────────────────┘│
│                             │
│  DEVICE                     │
│  ┌─────────────────────────┐│
│  │ Transfer to New Phone ▶ ││
│  │─────────────────────────││
│  │ Change PIN (USB)      ▶ ││  ← Android only
│  │─────────────────────────││
│  │ Flash Firmware (USB)  ▶ ││  ← Android only
│  └─────────────────────────┘│
│                             │
│  ABOUT                      │
│  ┌─────────────────────────┐│
│  │ Version            1.0  ││
│  └─────────────────────────┘│
│                             │
└─────────────────────────────┘
```

**Sections:**

1.  **Proximity**
    *   **Background Unlock toggle:** Enables/disables the background BLE scanning service. On iOS, toggling ON checks location permission and prompts if not yet granted.
    *   **Unlock Distance slider:** Maps to the RSSI unlock threshold. Displayed in human-readable terms ("~2m") with the raw dBm value below. Range: -50 to -85 dBm. Default: -65 dBm.
    *   **Lock Distance slider:** Maps to the RSSI lock threshold. Range: -60 to -95 dBm. Default: -75 dBm.
    *   **Validation:** The lock threshold must always be at least 10 dBm below the unlock threshold (enforcing the hysteresis gap from Section 3.3). If the user drags one slider past the constraint, the other slider auto-adjusts.

2.  **Keys (Inline Key Management)**

    On first render, Pipit queries `SLOTS?` via the Management Command characteristic (triggering SMP pairing + `IDENTIFY` if not already connected) and populates the slot rows from the JSON response. Rows are always shown for all 4 slots. Each phone slot (1–3) displays a **tier label** below the device name — `OWNER` or `GUEST` in small caps, muted secondary color — so the owner can see the access hierarchy at a glance.

    *   **Slot 0 (Uguisu):** Shown with a key icon (🔑) and the name "Uguisu".
        *   **iOS:** Non-interactive. A subtle label *"Manage via Whimbrel"* indicates USB management is not available on iOS.
        *   **Android:** A **three-dot menu (⋮)** with:
            *   **Replace** — For swapping in a new physical Uguisu unit. This is an automated two-step flow:
                1. Prompts the user to connect the new fob via USB-C OTG, and provisions the generated Slot 0 key into the new fob via CDC serial (`PROV:0:<new_key>:0:Uguisu`).
                2. Pipit then automatically sends the same `PROV` command to Guillemot via the BLE Management Command characteristic to sync the vehicle with the new fob. The old fob is immediately locked out.
            *   No Rename or Delete options. The hardware fob's name is always "Uguisu" and Slot 0 cannot be vacated.

    *   **Slot 1 (owner's own slot):** Shows the slot number and device name. **No three-dot menu** — the owner cannot replace or delete their own slot from here. Use "Transfer to New Phone" in the DEVICE section to migrate.

    *   **Active guest slots (2–3):** Show the slot number and device name. A **three-dot menu button (⋮)** with:
        *   **Rename** — Opens a text input dialog (max 24 characters). On confirm, sends `RENAME:<slot>:<new_name>`.
        *   **Replace** — Launches the Replace Flow (Section 10.7). Revokes this slot and provisions a new phone in its place.
        *   **Delete** — Confirmation dialog: *"Revoke <name>? This device will be permanently locked out."* On confirm, sends `REVOKE:<slot>`. The row transitions to an empty-slot state.

    *   **Empty guest slots (2–3):** Show only a centered **⊕** icon. Tapping the row launches the Provision Guest Phone flow (Section 10.6).
    *   **Empty Slot 1:** Should not normally occur (Slot 1 is provisioned during initial Whimbrel setup). If it somehow appears empty, the ⊕ icon is not shown — Slot 1 can only be provisioned via Whimbrel.

3.  **Device**
    *   **Transfer to New Phone →** launches the Migration Flow (Section 10.8). This is the happy-path device upgrade where the owner has both phones in hand.
    *   **Change PIN (USB) →** *(Android only, hidden on iOS)* launches the Change PIN flow (Section 10.9). Requires USB-C OTG connection to Guillemot since `SETPIN` is serial-only (Section 6.1). On iOS, users must change the PIN via Whimbrel.
    *   **Flash Firmware (USB) →** *(Android only, hidden on iOS)* launches the USB Flashing flow (Section 10.10). Covers Guillemot `.uf2` flashing and Uguisu CDC serial provisioning.

4.  **About**
    *   App version, build number. Tap-and-hold for debug info (BLE state, stored slot ID, counter value).

---

### 10.5.2 Guest Settings (Slot 2–3)

A stripped-down variant with no key management, no USB operations, and no PIN access. The guest controls only their local proximity preferences and can transfer their own key.

```
┌─────────────────────────────┐
│  Settings                 ✕ │
│─────────────────────────────│
│                             │
│  PROXIMITY                  │
│  ┌─────────────────────────┐│
│  │ Background Unlock  [ON] ││
│  │─────────────────────────││
│  │ Unlock Distance   ━━●━━ ││
│  │ (~2m / -65 dBm)        ││
│  │─────────────────────────││
│  │ Lock Distance     ━●━━━ ││
│  │ (~5m / -75 dBm)        ││
│  └─────────────────────────┘│
│                             │
│  YOUR KEY                   │
│  ┌─────────────────────────┐│
│  │ Slot 2 · Guest 1       ││
│  │ Transfer to New Phone ▶ ││
│  └─────────────────────────┘│
│                             │
│  ABOUT                      │
│  ┌─────────────────────────┐│
│  │ Version            1.0  ││
│  └─────────────────────────┘│
│                             │
└─────────────────────────────┘
```

**Sections:**

1.  **Proximity** — Identical to owner. These are phone-local settings (stored in `UserDefaults` / `SharedPreferences`) and don't touch management. Guests have full control over their own proximity unlock behaviour.

2.  **Your Key** — A single-row section showing the guest's own slot ID and name. No three-dot menu, no slot list, no visibility into other slots.
    *   **Transfer to New Phone →** launches the Migration Flow (Section 10.8). The guest can migrate their own key to a new phone via QR. Since guest slots use plaintext QR (Section 7.1.1), the migration QR is also **unencrypted** — no PIN prompt during transfer.

3.  **About** — Same as owner. Tap-and-hold for debug info.

---

### 10.6 Provision Guest Phone Flow

Launched from Settings by tapping an **empty guest slot row (⊕)** (Slot 2 or 3). Since guest slots use unencrypted QR codes (Section 7.1.1), this flow requires **no PIN entry** from either party.

**Step 1 — Confirm**
```
┌─────────────────────────────┐
│                             │
│   Add a guest key?          │
│                             │
│   This will create a key    │
│   for Slot 2 (Guest 1).    │
│   The guest will be able    │
│   to lock and unlock only.  │
│                             │
│        [ Create Key ]       │
│        [ Cancel ]           │
│                             │
└─────────────────────────────┘
```
*   The target slot and default name are pre-determined: Slot 2 → "Guest 1", Slot 3 → "Guest 2".
*   No name input prompt. The owner can rename the slot later from the three-dot menu if desired.

**Step 2 — Provisioning & QR Generation**

Pipit executes the following automatically:
1.  Generates a random 16-byte AES key using the platform's secure random generator (`SecRandomCopyBytes` on iOS, `SecureRandom` on Android).
2.  Sends `PROV:<slot>:<key>:0:Guest 1` via the Management Command characteristic.
3.  Generates a **plaintext QR code**: `immogen://prov?slot=2&key=<hex>&ctr=0&name=Guest%201`

**Step 3 — QR Display**
```
┌─────────────────────────────┐
│                             │
│   Scan this on the          │
│   guest's phone             │
│                             │
│   ┌───────────────────┐     │
│   │                   │     │
│   │    [QR Code]      │     │
│   │                   │     │
│   └───────────────────┘     │
│                             │
│   The guest just needs to   │
│   scan — no PIN required.   │
│                             │
│        [ Done ]             │
│                             │
└─────────────────────────────┘
```
*   The QR contains the slot key in plaintext. No PIN is needed by the recipient.
*   **"Done"** dismisses the flow and returns to Settings. The slot row now shows "Guest 1" with an active indicator.

---

### 10.7 Replace Flow

Launched from the **three-dot menu → Replace** on an active slot that is *not* the user's own. This is the break-glass path for replacing a lost or compromised device. It combines revocation + provisioning + QR generation in a single sequence.

**Step 1 — Confirm Revocation**
```
┌─────────────────────────────┐
│                             │
│   ⚠ Replace "Jamie's       │
│   iPhone" (Slot 1)?         │
│                             │
│   This will permanently     │
│   lock out the old device   │
│   and create a new key      │
│   for a replacement phone.  │
│                             │
│   [ Replace ]               │
│   [ Cancel ]                │
│                             │
└─────────────────────────────┘
```

**Step 2 — Revoke, Provision & QR Generation**

Pipit executes automatically:
1.  `REVOKE:<slot>` — invalidates the old key.
2.  Generates a new random 16-byte AES key.
3.  `PROV:<slot>:<new_key>:0:<default_name>` — provisions the slot with the new key, counter reset to 0. Name is restored to the slot's default ("Guest 1" / "Guest 2" for guest slots; owner can edit after).
4.  Generates QR:
    *   **Guest slot (2–3):** Plaintext QR (no PIN, no Argon2id). `immogen://prov?slot=2&key=<hex>&ctr=0&name=Guest%201`
    *   **Owner slot (1):** PIN-encrypted QR (Argon2id, same as Section 7.1). Prompts the owner for their PIN before generating.

**Step 3 — QR Display**
*   Same layout as Provision Flow Step 3. For guest replacements, the display notes *"No PIN required."* For owner replacement, it notes the recipient will need the PIN.
*   **"Done"** returns to Settings. The slot row shows the default name.

**Self-Provisioning Recovery Variant:** When the Replace flow is entered from the **Onboarding camera screen → "Phone recovery >"**, the current phone has no key. The app displays an explicit blocker prompt before proceeding:
*   *"Please unlock your vehicle with your Uguisu key fob or a guest phone key to authorize recovery."*
Once the user confirms the vehicle is unlocked:
1.  Pipit connects to Guillemot and authenticates via SMP PIN (OS prompt).
2.  Pipit queries `SLOTS?` and displays the active phone slots for the user to choose which device to recover.
3.  Pipit automatically executes the `RECOVER:<slot>` command with a newly generated key (as per Section 7.3). 
4.  The new key is stored directly in the local secure keystore (no QR needed — the key is for this phone) and Pipit proceeds to the onboarding Done screen (Step 5).

---

### 10.8 Migration Flow (Transfer to New Phone)

Launched from Settings → "Transfer to New Phone". This is the happy-path device upgrade described in Section 7.2. The user has both phones in hand.

**Step 1 — Confirm Intent**
```
┌─────────────────────────────┐
│                             │
│   Transfer your key to a    │
│   new phone?                │
│                             │
│   This will generate a QR   │
│   code for your new phone   │
│   to scan. After the        │
│   transfer, this phone      │
│   will no longer work as    │
│   a key.                    │
│                             │
│   [ Generate QR Code ]      │
│   [ Cancel ]                │
│                             │
└─────────────────────────────┘
```

**Step 2 — PIN Entry (Owner Only)**
*   **Owner (Slot 1):** Standard 6-digit PIN input. The PIN derives the Argon2id encryption key for the QR payload. Proceeds to Step 3.
*   **Guest (Slot 2–3):** This step is **skipped entirely**. The migration QR for guest slots is plaintext (same as Section 7.1.1) — no PIN needed. Proceeds directly to Step 3.

**Step 3 — QR Display**
```
┌─────────────────────────────┐
│                             │
│   Scan this on your         │
│   new phone                 │
│                             │
│   ┌───────────────────┐     │
│   │                   │     │
│   │    [QR Code]      │     │
│   │                   │     │
│   └───────────────────┘     │
│                             │
│   Open Pipit on your new    │
│   phone and scan this code. │
│                             │
│   [ Done — I've Scanned ]   │
│   [ Cancel ]                │
│                             │
└─────────────────────────────┘
```
*   The QR encodes the `immogen://prov?` URI with the encrypted slot key, **current counter value**, slot ID, name, and Argon2id salt. The counter is included so the new phone picks up exactly where the old phone left off (no desync).

**Step 4 — Confirmation & Key Deletion**
*   Tapping **"Done — I've Scanned"** triggers a confirmation dialog: *"Are you sure? The key will be permanently deleted from this phone."*
*   On confirm: the slot key is deleted from the secure keystore. Pipit returns to the Onboarding camera screen (it no longer has a valid key).
*   **"Cancel"** at any point aborts without deleting anything.

---

### 10.9 Change PIN (Android Only)

Launched from Settings → "Change PIN (USB)". Requires a USB-C OTG connection to Guillemot because `SETPIN` is a serial-only command (Section 6.1). This flow is **hidden on iOS** — iOS users must change the PIN via Whimbrel.

**Step 1 — Connect Guillemot via USB**
```
┌─────────────────────────────┐
│                             │
│   Change Management PIN     │
│                             │
│   Connect Guillemot via     │
│   USB-C OTG to continue.    │
│                             │
│       ○ Waiting for USB...  │
│                             │
└─────────────────────────────┘
```
*   Pipit listens for a CDC serial device via `usb-serial-for-android`. On detection: *"Guillemot connected."* Proceeds to Step 2.

**Step 2 — Enter New PIN**
```
┌─────────────────────────────┐
│                             │
│   Enter new 6-digit PIN     │
│                             │
│     ┌─┐┌─┐┌─┐┌─┐┌─┐┌─┐    │
│     │ ││ ││ ││ ││ ││ │    │
│     └─┘└─┘└─┘└─┘└─┘└─┘    │
│                             │
│   Confirm new PIN           │
│                             │
│     ┌─┐┌─┐┌─┐┌─┐┌─┐┌─┐    │
│     │ ││ ││ ││ ││ ││ │    │
│     └─┘└─┘└─┘└─┘└─┘└─┘    │
│                             │
│        [ Change PIN ]       │
│        [ Cancel ]           │
│                             │
└─────────────────────────────┘
```
*   Two-field entry with confirmation. Both must match to proceed.

**Step 3 — Confirmation**
*   Pipit sends `SETPIN:<6digits>` via USB serial.
*   On success: *"PIN changed. All phones will need the new PIN to pair for management in future sessions."*
*   **Important note displayed:** *"Existing BLE bonds are not affected. Phones that are already paired will continue to work. The new PIN is only needed when a phone pairs for management access for the first time, or after clearing its Bluetooth pairing data."*

---

### 10.10 USB Flashing (Android Only)

Launched from Settings → "Flash Firmware (USB)". This section is **hidden entirely on iOS** since iOS does not support USB OTG host mode for UF2 mass storage or CDC serial.

```
┌─────────────────────────────┐
│  ◀ Flash Firmware           │
│─────────────────────────────│
│                             │
│   Connect your device       │
│   via USB-C OTG.            │
│                             │
│  ┌─────────────────────────┐│
│  │                         ││
│  │  [ Flash Guillemot ]    ││
│  │  .uf2 firmware update   ││
│  │                         ││
│  └─────────────────────────┘│
│  ┌─────────────────────────┐│
│  │                         ││
│  │  [ Flash Uguisu ]       ││
│  │  firmware + key flash   ││
│  │                         ││
│  └─────────────────────────┘│
│                             │
└─────────────────────────────┘
```

**10.10.1 Flash Guillemot (UF2)**

Flashes the Guillemot immobilizer firmware via USB OTG using the UF2 mass storage protocol.

1.  The user connects Guillemot to the Android phone via USB-C OTG cable and boots Guillemot into UF2 bootloader mode (double-tap reset).
2.  Pipit detects the UF2 mass storage volume via `libaums` (USB mass storage library for Android) and displays: *"Guillemot bootloader detected."*
3.  Pipit provides a file picker to select the `.uf2` firmware file, or bundles the latest firmware in the app assets.
4.  **"Flash"** → Pipit copies the `.uf2` file to the root of the mass storage volume. Guillemot automatically reboots with the new firmware.
5.  Progress bar during file copy. On completion: *"Guillemot firmware updated."*

**10.10.2 Flash Uguisu (CDC Serial)**

Flashes the Uguisu hardware fob firmware and provisions its Slot 0 key via USB OTG CDC serial.

1.  The user connects the Uguisu fob (via its XIAO nRF52840 USB-C) to the Android phone via USB-C OTG cable.
2.  Pipit opens a CDC serial connection using `usb-serial-for-android` and detects the Uguisu bootloader or serial console.
3.  **Firmware flash:** Pipit sends the compiled firmware binary via the nRF52840's serial DFU protocol. Progress bar during transfer.
4.  **Key provisioning:** After firmware flash (or if firmware is already current), Pipit can send serial commands to configure Uguisu's Slot 0 AES key via the `PROV:0:<key>:0:Uguisu` command format. *(Note: To complete the pairing, Pipit must simultaneously send this same `PROV` command to Guillemot over BLE, as described in Section 10.5.1).*
5.  On completion: *"Uguisu firmware updated and key provisioned."*

---

### 10.11 State Diagram — Home Screen

The Home screen 3D model and disconnect overlay reflect a combined state machine:

```
                    ┌──────────────────┐
          ┌────────▶│  Disconnected    │◀─── No beacon detected
          │         │  Overlay: ON     │
          │         │  Model: frozen   │
          │         └──────┬───────────┘
          │                │ Beacon detected + GATT connected
          │                ▼
          │         ┌──────────────────┐
          │    ┌───▶│  Connected       │
          │    │    │  + Locked        │
          │    │    │  Overlay: OFF    │
          │    │    └──────┬───────────┘
          │    │           │ User tap OR RSSI ≥ unlock threshold
          │    │           ▼
          │    │    ┌──────────────────┐
          │    │    │  Connected       │
          │    │    │  + Unlocked      │
          │    │    │  LED: off (idle) │
          │    │    └──────┬───────────┘
          │    │           │ User long press OR RSSI ≤ lock threshold
          │    │           │   OR beacon lost
          │    └───────────┘
          │                │ Beacon lost entirely
          └────────────────┘
```

**Key behaviors:**
*   The 3D model's LED is always off at rest — there is no persistent visual for lock/unlock state. The lock/unlock state is tracked internally and inferred from the Guillemot beacon UUID (Locked UUID vs Unlocked UUID, Section 3.2), but the model only shows LED flashes during actions.
*   When proximity mode is ON, the model plays the corresponding flash animation when a background service action fires (e.g., if the background service auto-unlocked while the app is foregrounded, the model plays the green flash).
*   The disconnect overlay and model interaction are driven by the same BLE event stream — there is no separate "manual mode" vs "proximity mode" state machine. Proximity mode simply automates the same gesture based on RSSI.

---

### 10.12 Error & Edge Case Handling

| Scenario | Behavior |
|---|---|
| **BLE off** | Disconnect overlay shows `✕ Bluetooth is off`. Tapping deep-links to OS Bluetooth settings. |
| **Location permission denied (iOS)** | Proximity toggle in Settings shows a warning: *"Proximity unlock requires 'Always Allow' location. Tap to open Settings."* The app still works as a manual key fob. |
| **Guillemot not found** | Disconnect overlay shows `○ Disconnected`. No timeout — overlay stays until beacon is detected. |
| **Management connection rejected (wrong PIN)** | OS-level SMP failure. Pipit shows: *"Pairing failed. Check your PIN and try again."* After 10 failures, Guillemot enters hard lockout (Section 5.3). Pipit shows: *"Device locked. Connect via USB to reset."* |
| **All phone slots full (provision attempt)** | All ⊕ rows are replaced by active device rows. The user must **Delete** an existing slot before provisioning a new phone. No empty slot = no ⊕ icon shown. |
| **Replace own slot attempted (owner)** | The **Replace** and **Delete** options are hidden in the three-dot menu for the owner's own slot (Slot 1). The owner must use "Transfer to New Phone" instead. |
| **Guest attempts restricted action** | If a guest somehow reaches a restricted management command (e.g., via a race condition or protocol manipulation), Guillemot returns `{"status":"error","code":"FORBIDDEN","msg":"guest slot"}`. Pipit shows: *"This action requires owner access."* |
| **IDENTIFY fails (wrong key / corrupted keystore)** | Guillemot returns MIC failure. Pipit shows: *"Identity verification failed. Your key may be corrupted. Contact the device owner."* Management session remains unbound. |
| **QR scan fails repeatedly** | After 3 failed scans, show a help link: *"Having trouble? Make sure the QR code is well-lit and fully visible."* |
| **Argon2id KDF slow on old hardware** | QR decryption animation pauses at the convergence phase and holds until KDF completes. No timeout — the animation simply waits. |
| **USB OTG device not detected (Android)** | Flash Firmware screen shows: *"No device detected. Make sure it's connected via USB-C OTG and in bootloader mode."* |
| **Change PIN — USB disconnected mid-write** | Pipit shows: *"Connection lost. PIN may not have been saved. Reconnect and try again."* The old PIN remains valid unless `SETPIN` succeeded before disconnect. |
| **Slot 0 Replace — Uguisu not connected via USB (Android)** | The Replace action prompts: *"Connect the new Uguisu fob via USB-C OTG."* Waits for USB detection before proceeding. |
| **Counter overflow** | The 4-byte counter supports ~4 billion operations. No UI handling needed for practical use. |

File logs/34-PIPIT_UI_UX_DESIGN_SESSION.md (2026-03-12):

# Pipit UI/UX Design Session — Summary

*Date: 2026-03-11*

**Context:** Iterative design session defining the complete UI/UX architecture for the Pipit companion app, filling the last major gap in the master architecture doc (log 33). This session also surfaced and resolved a multi-user access control model that fed back into the core protocol design (Sections 2, 5, 6, 7 of log 33).

---

## 1. Foundation Decisions

Three initial design questions were resolved:

| Decision | Choice |
|---|---|
| Navigation model | Single-screen + modal sheets (utility app feel, not tab bar) |
| Primary interaction | Single toggle button (later evolved into 3D model) |
| Theme | System-follows (auto dark/light) |

---

## 2. 3D Uguisu Model as Primary Interface

The flat lock/unlock toggle button was replaced with a **photorealistic 3D model of the Uguisu hardware fob** as the home screen's sole interactive element. This reinforces the mental model that Pipit *is* the fob.

**Interaction:**
- **Tap** → Unlock (fire-and-forget AES-CCM payload)
- **Long press (700 ms)** → Lock (fires automatically at threshold, no release needed — matching `UGUISU_LONG_PRESS_MS` in firmware)

**Visual behaviour matches real Uguisu fire-and-forget:**
- LED is **always off at rest** — no persistent locked/unlocked visual distinction
- Unlock → green LED flash once (100 ms in, 200 ms hold, 200 ms out), button depresses, springs back
- Lock → red LED flash once, same timing
- No radial progress ring during long press (rejected as a design element)

**Rendering:** RealityKit (iOS) / SceneView+Filament (Android). `.usdz` + `.glb` assets. IBL environment lighting. LED is a separately addressable emissive mesh (`led_rgb`) controlled at runtime. Gyroscope parallax tilt (±5°, optional). Model depends on enclosure CAD (TBD); dev placeholder uses PCB dimensions.

**Haptics & sound:** Single heavy haptic at 700 ms lock threshold. Light haptic on tap unlock. Mechanical click sounds (~40–60 ms) mimicking SKQGABE010 tactile switch. Sound respects silent mode (`.ambient` session category on iOS, `getRingerMode()` check on Android).

---

## 3. Home Screen — Stripped Clean

All status text, slot labels, and proximity toggles were removed from the home screen. Only three elements remain:

1. **Gear icon** (top-left) → opens Settings
2. **3D Uguisu model** (center) → lock/unlock
3. **Hint label** ("Tap · Hold to lock") → shown until first lock, then hidden permanently

**Disconnect overlay:** When Guillemot is out of range, a system-theme-colored semi-transparent overlay (white 60% in light mode, black 60% in dark mode) covers the screen with "○ Disconnected" centered. Model visible but non-interactive beneath. Gear icon remains accessible above overlay.

**Settings transition:** Tapping the gear icon triggers a 3D flip animation — the Uguisu model rotates 180° on Y-axis, its back face cross-fades into the Settings content pane. Reverse on close.

---

## 4. Onboarding — Camera-First

Steps 1 (welcome) and 2 (QR scan) were merged. The app launches **directly into a full-screen camera** with a darkened overlay and a transparent QR-sized viewfinder window.

- Instruction text: *"Scan from Whimbrel"*
- Recovery link: *"recover key from lost phone >"* (bottom, subtle)
- Non-Immogen QR codes are **silently ignored** (no error toast)
- QR format detection determines flow branching:
  - Encrypted QR (`salt` + `ekey` fields) → PIN entry → Argon2id decryption
  - Plaintext QR (`key` field, guest provisioning) → skip PIN entirely

**QR decryption animation (~1s):** Dissolve (QR modules scatter as particles) → Convergence (particles re-converge, color-shift to accent) → Resolve (snap into key icon, haptic). KDF runs concurrently; animation pauses if hardware is slow.

**Location permission (iOS only):** Explains "Always Allow" requirement for iBeacon proximity unlock. Can be skipped.

**Done screen:** Shows all 4 slots (0–3) with tier labels (`OWNER` / `GUEST`) and the user's slot highlighted.

---

## 5. Access Tier Model

Emerged from a discussion about multi-user PIN management. The core realization: the 6-digit management PIN gates SMP pairing (BLE management access), but lock/unlock uses the Unlock/Lock characteristic (Write Without Response, no SMP, no PIN). Guest users who only lock/unlock never need the PIN.

### Slot Tiers

| Slot | Tier | Default Name | PIN Knowledge | Management Access |
|---|---|---|---|---|
| 0 | Hardware | `Uguisu` | N/A | None (USB-only via Whimbrel/Android OTG) |
| 1 | Owner | *(set during onboarding)* | Yes | Full |
| 2 | Guest | `Guest 1` | No | None (lock/unlock only) |
| 3 | Guest | `Guest 2` | No | None (lock/unlock only) |

Tier is implicit from slot number — no additional metadata stored.

### The `IDENTIFY` Command

Guillemot can't determine which slot is connecting for management from SMP alone (SMP proves PIN knowledge, not slot identity). New command added:

- Phone sends a 14-byte AES-CCM payload (same format as lock/unlock) with command byte `0x03` through the Management Command characteristic
- Guillemot decrypts using the claimed slot's key — if MIC valid + counter valid, session is bound to that slot
- All subsequent management commands are gated by the identified tier

| Command | Owner | Guest | No IDENTIFY |
|---|---|---|---|
| `IDENTIFY` | ✓ | ✓ | N/A |
| `SLOTS?` | ✓ | ✓ | ✓ (read-only) |
| `PROV` | ✓ | ✗ | ✗ |
| `REVOKE` | ✓ | ✗ | ✗ |
| `RENAME` (own slot) | ✓ | ✓ | ✗ |
| `RENAME` (other slot) | ✓ | ✗ | ✗ |

### Guest Provisioning — Unencrypted QR

Guest QR codes are **plaintext** (no Argon2id, no PIN):
```
immogen://prov?slot=2&key=<hex>&ctr=0&name=Guest%201
```

vs owner/migration (encrypted):
```
immogen://prov?slot=1&salt=<hex>&ekey=<encrypted_key_hex>&ctr=0&name=iPhone
```

The scanning phone distinguishes by field presence (`key` = plaintext, `ekey` + `salt` = encrypted). Security trade-off accepted: intercepted guest QR exposes the slot key, but (a) exchange is in-person, (b) owner can revoke at any time, (c) guest key grants no management access.

---

## 6. Settings — Owner vs Guest

Two distinct settings panes rendered based on the stored slot ID.

### Owner Settings (Slot 1)

| Section | Contents |
|---|---|
| **Proximity** | Background Unlock toggle, Unlock Distance slider, Lock Distance slider (10 dBm hysteresis enforced) |
| **Keys** (inline) | All 4 slots with tier labels. Slot 0: ⋮ Replace via USB (Android). Slot 1: own slot, no ⋮. Guest slots: ⋮ Rename/Replace/Delete. Empty slots: ⊕ → Provision Guest flow |
| **Device** | Transfer to New Phone, Change PIN via USB (Android), Flash Firmware via USB (Android) |
| **About** | Version, debug info on tap-hold |

### Guest Settings (Slot 2–3)

| Section | Contents |
|---|---|
| **Proximity** | Same as owner (phone-local settings) |
| **Your Key** | Single row: own slot name + "Transfer to New Phone" |
| **About** | Version |

No key management, no slot list, no USB operations, no PIN access.

---

## 7. Key Management Flows

### Provision Guest Phone (from ⊕ on empty slot)
Confirm → keygen → `PROV:<slot>:<key>:0:Guest N` → plaintext QR display. No name prompt (defaults to "Guest 1"/"Guest 2"), no PIN. One-tap flow.

### Replace (from ⋮ on active slot)
Confirm revocation → `REVOKE` → keygen → `PROV` → QR (plaintext for guest, encrypted for owner). Default name restored. Self-Provisioning Variant for "recover key from lost phone" onboarding path: connects to Guillemot via SMP, picks slot to replace, provisions self (no QR).

### Migration / Transfer to New Phone
Confirm → PIN entry (owner) or skip (guest) → QR display → "Done — I've Scanned" → confirm key deletion → key wiped, app returns to onboarding. QR includes current counter value for seamless takeover.

### Change PIN (Android only, USB serial)
Connect Guillemot via USB OTG → enter + confirm new 6-digit PIN → `SETPIN` via CDC serial. Existing SMP bonds unaffected; new PIN only applies to future pairing.

### USB Flashing (Android only)
Guillemot: UF2 mass storage via `libaums`. Uguisu: CDC serial firmware + key flash via `usb-serial-for-android`. Slot 0 replace (from ⋮ in key management) also routes through USB OTG.

---

## 8. Changes to Core Architecture (Sections 2, 5, 6, 7 of Log 33)

The UI/UX session surfaced protocol-level changes that were written back into the master architecture:

- **Section 2:** Slot tier table added (Hardware / Owner / Guest)
- **Section 5.5 (new):** `IDENTIFY` command spec, permission matrix, rationale for why SMP bonds alone are insufficient
- **Section 6.1:** `IDENTIFY` added to command transport table with tier gate column
- **Section 7.1.1 (new):** Guest provisioning with unencrypted QR, format differentiation (`key` vs `ekey`+`salt`)

All changes are reflected in log 33 as the single source of truth.

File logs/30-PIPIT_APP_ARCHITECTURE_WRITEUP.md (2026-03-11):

# Pipit: Companion App Architecture

*Date: 2026-03-10*

**Status:** Architectural Blueprint
**Scope:** Complete architecture for the Pipit companion iOS/Android app — tech stack, BLE design, key management, provisioning, and platform constraints.

---

## 1. Overview

**Pipit** is the companion app for the Immogen immobilizer ecosystem (following the ornithological naming: Guillemot, Uguisu, Whimbrel). It provides:

1. **Proximity Unlock (Background):** Low-power background BLE service that detects the vehicle and automatically unlocks Guillemot, with an adjustable proximity threshold.
2. **Active Key Fob (Foreground):** Manual lock/unlock UI, functionally identical to the Uguisu hardware fob.

Architecture: **Kotlin Multiplatform (KMP)** for shared business logic, with native UI (**UIKit** on iOS, **Jetpack Compose** on Android).

---

## 2. Tech Stack

### 2.1 Cross-Platform Core: KMP

Rather than duplicating business logic (Swift + Kotlin) or wrapping the C++ firmware codebase (`immo_crypto.cpp`) via JNI/Objective-C++, Pipit uses KMP.

* Native Kotlin on Android; compiles to a Swift-friendly native framework on iOS.
* Modern memory-safe environment vs. manual memory management through C++ wrappers.
* **Trade-off:** The C++ AES-CCM (RFC3610) crypto and MAC logic must be ported to pure Kotlin. The KMP implementation will be exhaustively unit-tested against the existing C++ test vectors for bit-for-bit parity.

### 2.2 UI: Platform-Native (Compose & UIKit)

No cross-platform UI frameworks (Flutter, React Native). BLE, camera (QR scanning), and secure enclave access are deeply intertwined with UI/UX — native toolkits ensure reliable platform API integration. UIKit is preferred over SwiftUI on iOS for mature BLE lifecycle management and finer control over background state transitions.

---

## 3. Key Slot Architecture

Guillemot supports **4 key slots** (0–3), each with an independent 16-byte PSK and monotonic counter for replay protection. Slot 0 is reserved for the Uguisu hardware fob; Slots 1–3 are for Pipit instances.

This solves the counter desync problem: if Uguisu and Pipit shared a single key/counter, unlocking via one would advance Guillemot's counter, causing the other device's payloads to be rejected until it "catches up." Independent slots eliminate this entirely.

When all slots are occupied, a new device cannot be provisioned until an existing slot is revoked.

---

## 4. BLE Architecture

### 4.1 The iOS Background Advertising Problem

The intuitive approach — phone as BLE Peripheral broadcasting its presence, Guillemot as Central scanning — fails on iOS. When backgrounded, iOS strips Manufacturer Data and hashes custom Service UUIDs into an undocumented, proprietary "overflow area." Guillemot (nRF52840) cannot decode this proprietary hash.

### 4.2 Solution: Guillemot as Advertiser, Pipit as Scanner

To achieve reliable background wake-ups on both platforms, the BLE roles are flipped:

1. **Guillemot (Central + Peripheral):**
   * Continues 5% duty-cycle scanning (25ms/500ms) for Uguisu fobs.
   * Simultaneously broadcasts a 500ms-interval beacon with a custom "Immogen Proximity" Service UUID.
2. **Pipit (Central/Scanner):**
   * Implements a **Stateful Beaconing** strategy to support both approach-to-unlock and walk-away-to-lock without continuous background wake-ups while riding.
   * **When Locked:** Scans for the "Immogen Proximity - Locked" UUID. On detection, it evaluates the beacon's RSSI against a user-configurable proximity threshold. If the signal is strong enough, it connects via GATT and sends the Unlock payload.
   * **When Unlocked:** Scans for the "Immogen Proximity - Unlocked" UUID. Monitors RSSI against the user's walk-away threshold. When RSSI drops below this threshold (or the beacon is lost entirely), it connects via GATT and sends the Lock payload.

**iOS caveats:** CoreBluetooth batches background scan delivery — latency ranges from sub-second to several minutes depending on iOS version, device state, and app recency. `CBCentralManagerScanOptionAllowDuplicatesKey` is ignored in background mode. Implementation must use `centralManager:willRestoreState:` for state restoration.

### 4.3 Why GATT (Not Connectionless)

Even with the roles flipped, Pipit cannot send its unlock payload connectionlessly — the BLE specification provides no mechanism for a scanner to transmit custom data (e.g., inside a Scan Request). Pipit must establish a GATT connection to write the payload.

### 4.4 GATT Characteristic Structure

Guillemot's GATT server exposes the "Immogen Proximity" service with three characteristics:

* **Unlock/Lock Command:** Pipit writes a 19-byte encrypted AES-CCM payload (identical structure to Uguisu's MSD). This is a "Write Without Response" (fire-and-forget), matching the blind-broadcast nature of the hardware fob.
* **Management Command:** Requires an **Authenticated Link** (MITM protection) via standard BLE Pairing PIN. Used for slot queries, revocation, provisioning, and PIN changes.
* **Management Response:** `Notify` characteristic to asynchronously return responses to management commands. Responses (like the output of `SLOTS?`) are formatted as JSON for trivial parsing in KMP and Web Bluetooth (e.g., `{"slots":[{"id":0,"used":true},{"id":1,"used":false}]}`).

### 4.5 Slot Identification via Prefix Byte

The 19-byte payload structure is: `[1-byte Prefix] [4-byte Counter] [10-byte MAC] [4-byte Ciphertext]`.
To avoid brute-forcing decryption across all 4 key slots, the 1-byte Prefix explicitly encodes both the Slot ID and the Command:
* **Upper 4 bits:** Slot ID (0-3)
* **Lower 4 bits:** Command (1 = Unlock, 2 = Lock)

Example: `0x11` explicitly tells Guillemot to pull the AES key for Slot 1 and verify an Unlock command. Slot 0 is strictly reserved for the Uguisu fob.

### 4.6 Unlock Latency (GATT Path)

Unlike Uguisu's connectionless broadcast (detected in a single scan window), Pipit's path involves sequential GATT operations post-wake:

| Step | Typical Latency |
|---|---|
| OS background scan delivery | Sub-second to minutes (variable) |
| GATT connection establishment | ~50–200 ms |
| Service & characteristic discovery | ~100–300 ms |
| Encrypted payload write + ACK | ~10–50 ms |
| `verify_payload()` + latch actuation | ~5–15 ms |
| **Total (post-wake)** | **~165–565 ms** |

The post-wake GATT path is near-instant. The dominant variable is OS scan delivery — proximity unlock via Pipit will not feel as instantaneous as a physical fob press, particularly on iOS.

---

## 5. Provisioning & Key Management

### 5.1 QR Code Provisioning & Migration

Pipit uses QR codes for two distinct scenarios: Initial Setup and Device Migration. The QR encodes the provisioning URI:

```
immogen://prov?slot=<n>&key=<hex>&ctr=<counter>&pin=<6digits>&name=<url_encoded_string>
```

* **High-Bandwidth, Air-Gapped Transfer:** QR codes safely move root keys without exposing them to unencrypted BLE sniffing.
* **Strict Keystore usage:** Slot keys and the management PIN are stored strictly in hardware-backed keystores (**Android Keystore** / **iOS Keychain**).
* **Device Migration:** When migrating to a new phone, Pipit displays a QR code containing the *current* counter value. The new phone scans it, and the old phone instantly deletes its local key. This transfers the credential perfectly without causing "Leapfrog" counter desyncs between two active phones.

### 5.2 Onboarding Flow (Whimbrel)

The initial provisioning is driven by Whimbrel over USB-C serial:

1. Flash Guillemot firmware via USB-C DFU. *(Skippable for pre-flashed devices.)*
2. Provision Uguisu (Slot 0): Generate key → flash to fob via serial → prompt disconnect.
3. Provision Guillemot (Slot 0): Flash same key via serial (`PROV:0:...:Uguisu Fob`). No management PIN set yet.
4. "Add a phone key?" — if declined, onboarding complete.
5. Set management PIN: User enters 6-digit PIN. Whimbrel sends PIN hash and provisions Slot 1 via serial (`PROV:1:...:iPhone`).
6. Display QR code for the phone to scan (with obscure/reveal controls).

### 5.3 BLE Key Management (Post-Installation)

Once a management PIN is set, Pipit can authenticate to Guillemot over BLE and perform:

* **Query slot status:** Read all 4 slots via `SLOTS?`. Guillemot returns JSON containing the user-assigned `name` (e.g. "Jamie's iPhone"), occupied status, and last-seen counter value.
* **Rename a slot:** Send `RENAME:<slot>:<name>` to update the friendly device name stored in Guillemot's flash without altering the AES key.
* **Revoke a slot:** Zero PSK, reset counter, and clear the name string, freeing it for re-provisioning.
* **Lost Phone Recovery:** Pipit queries `SLOTS?`, displays the friendly names of active devices, asks the user which device was lost, issues a `REVOKE` for that specific slot, and self-provisions into the newly vacated slot.
* **Provision/replace Uguisu fob (Slot 0):** Generate key → write to Slot 0 over BLE → flash to fob via USB-C. **Android only** (USB OTG via `usb-serial-for-android`); iOS requires Whimbrel on a laptop.
* **Change management PIN:** Requires current PIN.

### 5.4 Management PIN (For Stateless Whimbrel Access)

A **6-digit management PIN** enables BLE key management post-installation, avoiding vehicle teardown for routine operations. 

**Why a PIN?** It allows the Whimbrel web dashboard to manage keys over BLE without requiring Whimbrel to store or maintain permanent memory of the vehicle's cryptographically secure 16-byte slot keys. A user can connect via any browser supporting Web Bluetooth, enter the PIN, and perform emergency operations (like revoking a lost phone) completely statelessly.

**Security via BLE Pairing PIN:** Instead of a custom plaintext PIN challenge (which would expose new provisioning keys to passive BLE sniffers), the PIN acts as the **standard BLE Pairing PIN (SMP)**. When Whimbrel or Pipit attempts to read/write the Management characteristics, the OS automatically prompts for the 6-digit PIN, establishing a fully encrypted and MITM-protected BLE session before any commands are transmitted.

The PIN is only set when the first phone is provisioned — until then, Guillemot does not expose BLE management characteristics.

**Brute-force protection (Guillemot-enforced):**
* Exponential backoff after 3 consecutive failures: 5s → 10s → 20s → 40s → ...
* Hard lockout after 10 consecutive failures — BLE management disabled entirely. Recovery requires USB-C serial via Whimbrel.
* Successful PIN entry resets the failure counter.

Pipit must handle lockout feedback gracefully in its UI (display remaining wait time, indicate hard lockout state).

### 5.5 Recovery Fallback

USB-C serial via Whimbrel is the break-glass path for: all keys lost, PIN forgotten, or hard lockout triggered. Requires physical access to Guillemot's USB-C port (vehicle disassembly) — acceptable for a recovery-only path. Pipit should direct users to Whimbrel in these scenarios.

---
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

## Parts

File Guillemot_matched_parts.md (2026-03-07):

# Guillemot BOM - Matched Parts

## Matched Components

| Designator  | Comment | Footprint | Part Name | LCSC | Description / Specs | Qty | Type | Total Cost |
| --- | --- | --- | --- | --- | --- | --- | --- | --- |
| BZ1 | FUET-1230 | BUZ-SMD_L12.0-W12.0_FUET-1230 | FUET-1230 | C391037 | -20℃~~+70℃ 12mm 12mm 1V~~25V 3.3mm 3V 4kHz 5mA 75dB Passive (Externally Driven) Piezoelectric SMD,12x12mm Buzzers ROHS | 5 | Extended | $2.3640 |
| C1 | 10nF | 0603 | 0603B103K500NT | C57112 | 10nF 50V X7R ±10% 0603 Multilayer Ceramic Capacitors MLCC - SMD/SMT ROHS | 5 | Basic | $0.0140 |
| C2 | 100µF | 1210 | CL32A107MPVNNNE | C23742 | 100uF 10V X5R ±20% 1210 Multilayer Ceramic Capacitors MLCC - SMD/SMT ROHS | 5 | Extended | $1.5285 |
| C3,C4 | 1uF | 0603 | CL10A105KB8NNNC | C15849 | 1uF 50V X5R ±10% 0603 Multilayer Ceramic Capacitors MLCC - SMD/SMT ROHS | 5 | Basic | $0.0720 |
| D1 | BZT52C12-7-F | D_SOD-123 | BZT52C12-7-F | C124196 | -65℃~~+150℃ 100nA@1V 11.4V~~12.7V 12V 150Ω 25Ω 370mW Independent SOD-123 Zener Diodes ROHS | 5 | Extended | $0.5538 |
| D2 | BZT52C10-7-F | D_SOD-123 | BZT52C10-7-F | C155227 | -65℃~~+150℃ 10V 150Ω 200nA 20Ω 370mW 9.4V~~10.6V Independent SOD-123 Zener Diodes ROHS | 5 | Extended | $0.5085 |
| D3,D4 | 1N4148W | D_SOD-123 | 1N4148W | C81598 | 1.25V@150mA 100V 150mA 1uA@75V 2A 4ns 500mW Independent SOD-123 Switching Diodes ROHS | 10  | Basic | $0.1100 |
| D5 | SMBJ45A | D_SMB | SMBJ45A | C114005 | -65℃~+150℃ 1uA 45V 55.3V 600W@10/1000us 72.7V 8.3A@10/1000us TVS Unidirectional DO-214AA(SMB) ESD and Surge Protection | 5 | Extended | $0.4221 |
| PS1 | TPSM365R6V3RDNR | CONV_TPSM365R6V3RDNR | TPSM365R6V3RDNR | C18208843 | -40℃~~+125℃ 1MHz 2mm 3.3V 3.5mm 3.6V~~65V 4.5mm 4uA 600mA 80.2% Buck Overheat protection、Over Current Protection ±1.5% | 5 | Extended | $17.9375 |
| Q1 | IPB042N10N3G | TO-263-2 | IPB042N10N3G | C69300 | -55℃~+175℃ 1 N-channel 100V 117nC 137A 214W 3.5V 4.2mΩ@10V 41pF 8.41nF TO-263-3 MOSFETs ROHS | 5 | Extended | $3.7630 |
| Q2 | AO3422 | SOT-23 | AO3422 | C37130 | 1 N-channel 10A 12.6pF 160mΩ@4.5V 2V [3.3nC@4.5V](mailto:3.3nC@4.5V) 300pF 55V N-Channel SOT-23 MOSFETs ROHS | 5 | Extended | $1.1376 |
| Q3 | SI2309CDS | SOT-23 | SI2309CDS-T1-GE3 | C10493 | -55℃~+150℃ 1 P-Channel 1.6A 1.7W 20pF 210pF 28pF 3V [4.1nC@4.5V](mailto:4.1nC@4.5V) 450mΩ@4.5V 60V P-Channel SOT-23-3 MOSFETs ROHS | 5 | Extended | $1.1333 |
| Q4 | 2N7002 | SOT-23 | 2N7002 | C8545 | 1 N-channel 115mA 2.5V 225mW 50pF 5pF 5Ω@10V 60V SOT-23 MOSFETs ROHS | 5 | Basic | $0.0660 |
| Q5,Q6 | MMBT3904 | SOT-23 | MMBT3904(RANGE:100-300) | C20526 | -55℃~+150℃ 1 NPN 100 100nA 200mA 200mW 300MHz 300mV 40V 6V NPN SOT-23 Bipolar (BJT) ROHS | 5 | Basic | $0.0950 |
| R1,R2,R3,R7 | 100k | 0603 | 0603WAF1003T5E | C25803 | -55℃~+155℃ 100kΩ 100mW 75V Thick Film Resistor ±1% ±100ppm/℃ 0603 Chip Resistor - Surface Mount ROHS | 5 | Basic | $0.0280 |
| R4 | 1M | 0603 | 0603WAF1004T5E | C22935 | -55℃~+155℃ 100mW 1MΩ 75V Thick Film Resistor ±1% ±100ppm/℃ 0603 Chip Resistor - Surface Mount ROHS | 5 | Basic | $0.0065 |
| R5 | 10k | 0603 | 0603WAF1002T5E | C25804 | -55℃~+155℃ 100mW 10kΩ 75V Thick Film Resistor ±1% ±100ppm/℃ 0603 Chip Resistor - Surface Mount ROHS | 5 | Basic | $0.0065 |
| R6 | 4.7k | 0603 | 0603WAF4701T5E | C23162 | -55℃~+155℃ 100mW 4.7kΩ 75V Thick Film Resistor ±1% ±100ppm/℃ 0603 Chip Resistor - Surface Mount ROHS | 5 | Basic | $0.0065 |
| R8 | 472W | 2512 | RC2512JK-7W47RL | C136992 | -55℃~+155℃ 200V 2W 47Ω Thick Film Resistor ±200ppm/℃ ±5% 2512 Chip Resistor - Surface Mount ROHS | 5 | Extended | $0.5184 |
| U2 | SN74LVC2G02DCTR | MSOP-8_L2.9-W2.8-P0.65-LS4.0-BR | SN74LVC2G02DCTR | C94600 | -40℃~~+125℃ 1.2V、1.9V、2.3V、2.4V、3.8V 1.65V~~5.5V 1.7V~2V 10uA 2 2 300mV、400mV、450mV、550mV 32mA 32mA 4.4ns@5V,50pF 74LVC | 5 | Extended | $2.6565 |

## Unmatched Components

| Designator | Comment |
| --- | --- |
| U1 | XIAO-nRF52840-SMD |

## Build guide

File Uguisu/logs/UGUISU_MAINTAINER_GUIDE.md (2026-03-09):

# Uguisu Maintainer Guide: Resolving the `File` Naming Collision

## Background

Both the `Adafruit_LittleFS` library and `SdFat` library (which is included automatically by the `Adafruit TinyUSB Library` for Mass Storage support) declare a `File` class in the global C++ namespace. When building a project that uses LittleFS on the Adafruit nRF52 core with TinyUSB, this causes a fatal naming collision.

Historically, this issue was sidestepped by using a fragile Python script (`extra_script.py`) to intercept the framework compilation and inject a custom header to hide `SdFat`. 

However, this method is brittle and prone to breaking when PlatformIO or the underlying framework updates.

## The Solution

A much cleaner, native solution is to use TinyUSB's built-in configuration macros to completely disable Mass Storage Class (MSC) support, which prevents the framework from including `SdFat` in the first place.

This fix has now been integrated directly into the shared `ImmoCommon` library.

## How to Update Uguisu

To apply this cleaner fix to the Uguisu fob project, you need to update its `platformio.ini` to consume the new shared configuration file.

### 1. Ensure `ImmoCommon` is Updated
First, make sure the `ImmoCommon` submodule in your Uguisu repository is pulled to the latest commit containing `src/immo_tusb_config.h`.

### 2. Update `platformio.ini`
In the Uguisu `platformio.ini` file, perform the following modifications:

1. **Remove the extra script hack:**
   Delete the line that says `extra_scripts = pre:extra_script.py`. You can also safely delete the `extra_script.py` file and the `include_fix` directory from the repository.

2. **Add the SPI library dependency:**
   Because TinyUSB was implicitly resolving the `SPI.h` dependency for the build graph, disabling MSC can cause PlatformIO's Library Dependency Finder (LDF) to miss it. Add `SPI` explicitly to `lib_deps`.

3. **Configure LDF to search deeper:**
   Add `lib_ldf_mode = deep+` to ensure PlatformIO correctly parses dependencies inside the modified framework macros.

4. **Add the Build Flags:**
   Inject the new configuration file via `-D CFG_TUSB_CONFIG_FILE`. You must also explicitly add the `ImmoCommon/src` directory to the global include path so that the TinyUSB library can find it during compilation.

### Example `platformio.ini` Changes:

```ini
; ... existing config ...

lib_deps =
  afantor/Bluefruit52_Arduino
  adafruit/Adafruit TinyUSB Library
  SPI            ; <-- Add this

lib_ldf_mode = deep+   ; <-- Add this

build_flags =
  ; ... other flags ...
  -D CFG_TUSB_CONFIG_FILE=\"immo_tusb_config.h\"   ; <-- Add this
  -I ../../lib                            ; <-- Add this
  -I ".pio/libdeps/your_board_name/Adafruit TinyUSB Library/src"
```

Once these changes are made, the project will compile cleanly without the need for brittle python build scripts, and the `File` class will unambiguously resolve to `Adafruit_LittleFS`.

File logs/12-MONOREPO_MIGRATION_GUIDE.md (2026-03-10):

# Immogen Monorepo Migration Guide

*Date: 2026-03-09 23:28*

This guide describes how to merge Guillemot and Uguisu into the ImmoCommon repository, rename it to **Immogen**, and reconfigure releases. **Full git history is preserved** for all projects.

## Summary of changes

| Item | Before | After |
|---|---|---|
| Repo name | ImmoCommon | **Immogen** |
| Releases | Separate per project | **Single release** with both firmwares |
| Release artifacts | firmware.zip, firmware.hex per repo | guillemot-1.0.0.zip, guillemot-1.0.0.hex, uguisu-1.0.0.zip, uguisu-1.0.0.hex |
| Internal code | immo::, ImmoCommon.h | **Unchanged** (Option A) |

---

## Prerequisites

- Git 2.23+ (for `git subtree`)
- Clean working tree in all three repos
- Push any pending commits before starting
- **Back up** your work

---

## Target Layout

Use **uppercase** `Guillemot` and `Uguisu`; flatten firmware paths to `/Guillemot/firmware` and `/Uguisu/firmware` (no extra `guillemot/` or `uguisu/` subfolder).

```
Immogen/                              # single repo (renamed from ImmoCommon)
├── lib/                              # shared library (current ImmoCommon src)
│   ├── src/
│   │   ├── immo_crypto.cpp
│   │   ├── immo_provisioning.cpp
│   │   └── ...
│   └── tools/
├── Guillemot/                        # receiver (from Guillemot repo)
│   ├── firmware/                     # platformio project directly here
│   ├── *.kicad_*
│   └── ...
├── Uguisu/                           # fob (from Uguisu repo)
│   ├── firmware/                     # platformio project directly here
│   ├── *.kicad_*
│   └── ...
├── tools/                            # consolidated HTML tools from both projects
│   ├── led_visualizer.html            # from Uguisu
│   ├── ble_timing_simulator.html      # from Uguisu
│   └── buzzer_tuner.html              # from Guillemot
└── .github/
    └── workflows/
        └── release.yml
```

---

## Phase 1: Prepare ImmoCommon (pre-rename)

Work in a **fresh clone** to avoid touching your main workspace.

```bash
cd /tmp
git clone https://github.com/LPFchan/ImmoCommon.git immogen-monorepo
cd immogen-monorepo
```

### 1.1 Restructure: move src and tools into lib/

```bash
mkdir -p lib
git mv src lib/
git mv tools lib/ 2>/dev/null || true
git add -A
git commit -m "Restructure: move src and tools into lib/ for monorepo layout"
```

---

## Phase 2: Add Guillemot with History

### 2.1 Add Guillemot subtree

```bash
git subtree add --prefix=Guillemot https://github.com/LPFchan/Guillemot.git main
```

### 2.2 Flatten firmware directory

```bash
mv Guillemot/firmware/guillemot/* Guillemot/firmware/
rm -rf Guillemot/firmware/guillemot
```

### 2.3 Remove Guillemot's ImmoCommon submodule

```bash
rm -rf Guillemot/firmware/lib/ImmoCommon
```

Delete `Guillemot/.gitmodules` (or remove the ImmoCommon entry) so the integrated tree doesn't appear as a submodule:

```bash
rm -f Guillemot/.gitmodules
```

### 2.4 Update Guillemot platformio.ini

Edit `Guillemot/firmware/platformio.ini`:

**Change:** Replace `-I lib/ImmoCommon/src` with `-I ../../lib/src`

### 2.5 Commit

```bash
git add Guillemot/
git commit -m "Integrate Guillemot: flatten firmware, remove lib submodule, point to in-tree lib"
```

---

## Phase 3: Add Uguisu with History

### 3.1 Add Uguisu subtree

```bash
git subtree add --prefix=Uguisu https://github.com/LPFchan/Uguisu.git main
```

### 3.2 Flatten firmware directory

```bash
mv Uguisu/firmware/uguisu/* Uguisu/firmware/
rm -rf Uguisu/firmware/uguisu
```

### 3.3 Remove Uguisu's ImmoCommon submodule

```bash
rm -rf Uguisu/firmware/lib/ImmoCommon
```

Delete `Uguisu/.gitmodules` (or remove the ImmoCommon entry):

```bash
rm -f Uguisu/.gitmodules
```

### 3.4 Update Uguisu platformio.ini

Edit `Uguisu/firmware/platformio.ini`:

**Change:** Replace `-I lib/ImmoCommon/src` with `-I ../../lib/src`

### 3.5 Consolidate tools to repo root

Move the three HTML tools to the new `tools/` directory at repo root:

```bash
mkdir -p tools
mv Uguisu/tools/led_visualizer.html tools/
mv Uguisu/tools/ble_timing_simulator.html tools/
mv Guillemot/tools/buzzer_tuner.html tools/
```

### 3.6 Commit

```bash
git add Uguisu/ Guillemot/ tools/
git commit -m "Integrate Uguisu: flatten firmware, remove submodule, consolidate tools to /tools"
```

---

## Phase 4: Single Release Workflow (Both Firmwares)

One tag (e.g. `v1.0.0`) builds **both** Guillemot and Uguisu and creates a single release with four artifacts:
- `guillemot-1.0.0.hex`
- `guillemot-1.0.0.zip`
- `uguisu-1.0.0.hex`
- `uguisu-1.0.0.zip`

### 4.1 Create `.github/workflows/release.yml`

```yaml
name: Release

permissions:
  contents: write

on:
  push:
    tags:
      - 'v*'

jobs:
  build-and-release:
    runs-on: ubuntu-latest
    steps:
      - name: Checkout
        uses: actions/checkout@v4

      - name: Set up Python
        uses: actions/setup-python@v5
        with:
          python-version: '3.11'

      - name: Install PlatformIO
        run: pip install -U platformio

      - name: Build Guillemot
        working-directory: Guillemot/firmware
        run: pio run

      - name: Build Uguisu
        working-directory: Uguisu/firmware
        run: pio run

      - name: Rename artifacts for release
        run: |
          V=${GITHUB_REF#refs/tags/v}
          cp Guillemot/firmware/.pio/build/seeed_xiao_nrf52840_bluefruit/firmware.hex guillemot-${V}.hex
          cp Guillemot/firmware/.pio/build/seeed_xiao_nrf52840_bluefruit/firmware.zip guillemot-${V}.zip
          cp Uguisu/firmware/.pio/build/seeed_xiao_nrf52840_bluefruit/firmware.hex uguisu-${V}.hex
          cp Uguisu/firmware/.pio/build/seeed_xiao_nrf52840_bluefruit/firmware.zip uguisu-${V}.zip

      - name: Create release
        uses: softprops/action-gh-release@v2
        with:
          tag_name: ${{ github.ref_name }}
          name: ${{ github.ref_name }}
          files: |
            guillemot-*.hex
            guillemot-*.zip
            uguisu-*.hex
            uguisu-*.zip
        env:
          GITHUB_TOKEN: ${{ secrets.GITHUB_TOKEN }}
```

### 4.2 Remove old workflow files

Delete any release workflows inside Guillemot and Uguisu; the single workflow at repo root replaces them.

---

## Phase 5: Rename ImmoCommon → Immogen

### 5.1 Rename GitHub repository

1. Go to **ImmoCommon** → **Settings** → **General**
2. Under "Repository name", change `ImmoCommon` to **Immogen**
3. Click **Rename**

### 5.2 Update local clone remote

```bash
git remote set-url origin https://github.com/LPFchan/Immogen.git
```

### 5.3 Update README and docs

- Replace "ImmoCommon" with "Immogen" in:
  - `README.md` (root)
  - `lib/` README if present
  - Any `Guillemot/` or `Uguisu/` docs that reference the repo
- Update GitHub URLs to `LPFchan/Immogen`
- Optionally add a note: "Immogen (formerly ImmoCommon) — shared library for the BLE immobilizer system"

### 5.4 Commit and push

```bash
git add README.md
git add -A
git commit -m "Rename project to Immogen"
git push origin main
```

---

## Phase 6: Update Whimbrel

Whimbrel fetches releases from GitHub. After migration, use the **Immogen** repo and expect one release with four assets.

### 6.1 Update release API base

In `Whimbrel/js/api.js` (or equivalent), change:

- From: separate fetch to `LPFchan/Guillemot` and `LPFchan/Uguisu`
- To: single fetch to `LPFchan/Immogen`

The existing filter `r.assets.some((a) => a.name.endsWith(".zip"))` still works, since each release will have multiple `.zip` assets.

### 6.2 Update asset selection

Releases now contain both device types per release:
- `guillemot-{version}.zip` and `guillemot-{version}.hex`
- `uguisu-{version}.zip` and `uguisu-{version}.hex`

**Important:** The current `releaseData.assets.find((a) => a.name.endsWith(".zip"))` returns the first `.zip` asset, which may not match the selected device. Update logic to:

1. Fetch the latest release from Immogen (once per device selection).
2. Filter assets by device type: fob → `uguisu-*.zip`, receiver → `guillemot-*.zip`.

Example:

```javascript
const prefix = fwSelectedDeviceName === "Guillemot" ? "guillemot" : "uguisu";
const zipAsset = releaseData.assets.find((a) => a.name.startsWith(prefix) && a.name.endsWith(".zip"));
```

### 6.3 Update config

In `Whimbrel/js/config.js`, add `GITHUB_REPO` and set it to `Immogen`:

```javascript
GITHUB_OWNER: "LPFchan",
GITHUB_REPO: "Immogen",
```

Update `fetchReleases` / `fetchDeviceReleases` to use `CONFIG.GITHUB_REPO` instead of hardcoded `"Guillemot"` or `"Uguisu"` when fetching from Immogen.

---

## Phase 7: Verify and Push

### 7.1 Build both firmwares locally

```bash
cd Guillemot/firmware
pio run
cd ../..

cd Uguisu/firmware
pio run
cd ../..
```

### 7.2 Verify history

```bash
git log --oneline -20
git log --oneline Guillemot/
git log --oneline Uguisu/
```

### 7.3 Push to remote

```bash
git push origin main
```

---

## Phase 8: Post-Migration Cleanup

1. **Archive Guillemot and Uguisu repos**
   - Settings → Danger Zone → Archive repository
   - Add README notice: "Merged into [Immogen](https://github.com/LPFchan/Immogen)."

2. **Update external links**
   - Docs, badges, or references to ImmoCommon or old repo URLs

3. **Release workflow setup**
   - Ensure `RELEASE_TOKEN` (or equivalent) secret exists if required for releases

---

## Release usage

After migration, tag and push to trigger a release:

```bash
git tag v1.0.0
git push origin v1.0.0
```

This builds both firmwares and creates a release with:
- `guillemot-1.0.0.hex`
- `guillemot-1.0.0.zip`
- `uguisu-1.0.0.hex`
- `uguisu-1.0.0.zip`

---

## Checklist

- [x] Phase 1: Restructure ImmoCommon (src → lib/)
- [x] Phase 2: subtree add Guillemot, flatten firmware, remove submodule, fix platformio.ini, delete .gitmodules
- [x] Phase 3: subtree add Uguisu, flatten firmware, remove submodule, consolidate tools to /tools, fix platformio.ini, delete .gitmodules
- [x] Phase 4: Single CI workflow (both firmwares, renamed artifacts)
- [x] Phase 5: Rename repo to Immogen, update docs
- [x] Phase 6: Update Whimbrel (Immogen, GITHUB_REPO, asset selection by device type)
- [ ] Phase 7: Build both, verify history, push
- [ ] Phase 8: Archive old repos, update links

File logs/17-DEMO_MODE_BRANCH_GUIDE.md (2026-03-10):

# Whimbrel: Syncing Main → Demo

*Date: 2026-03-10 01:53*

Documents how to bring `main` changes into the `demo` branch and re-enable demo flags.

---

## What Demo Mode Does

The `demo` branch runs without real hardware. All serial port operations, provisioning handshakes, and firmware flashing are simulated with timed delays. The UI and flow are otherwise identical to `main`.

Demo mode is activated by `window.WHIMBREL_DEMO = true` in `index.html`, which is read by `config.js` on load.

---

## Step 1: Merge Main

```bash
git checkout demo
git merge -X theirs main --no-edit
```

`-X theirs` accepts main's version for any conflicts, since main is the authoritative source. Demo flags are re-applied on top afterward.

### Verify the CSS was not corrupted

This is not optional. `-X theirs` has silently dropped CSS rules in a previous Whimbrel merge (March 2026): the `.release-item` and `.progress-container` blocks were replaced by a lone `.release-separator` from demo's side of the conflict. The page loaded fine but the firmware dropdown items were unstyled.

```bash
git diff main -- css/style.css
```

The only differences should be the `.demo-badge` block. If anything else is missing from main's side, restore it manually before proceeding.

---

## Step 2: Re-Apply Demo Flags

### `index.html`

Two changes:

1. Add `window.WHIMBREL_DEMO = true` **before** `config.js` loads:
```html
<script>window.WHIMBREL_DEMO = true;</script>
<script src="js/config.js"></script>
```

2. Add the demo badge to the tagline:
```html
<p class="tagline">Companion Web App for <a href="..." target="_blank">Immogen</a> (Guillemot + Uguisu) <span class="demo-badge" id="demo-badge" aria-hidden="true">Demo</span></p>
```

### `js/config.js`

Add `DEMO_MODE` immediately after the namespace declaration, before `CONFIG`:

```javascript
window.Whimbrel = window.Whimbrel || {};
window.Whimbrel.DEMO_MODE = typeof window !== "undefined" && window.WHIMBREL_DEMO === true;

window.Whimbrel.CONFIG = { ... };
```

### `js/serial.js`

In `isSupported()`, short-circuit for demo so the "unsupported browser" warning doesn't appear:

```javascript
window.Whimbrel.isSupported = function() {
  if (window.Whimbrel.DEMO_MODE) return true;
  return "serial" in navigator;
};
```

### `js/api.js`

In `fetchDeviceReleases()`, return a fake release before making any network call. Both asset names must be present so either device tile works:

```javascript
window.Whimbrel.fetchDeviceReleases = async function(repoName) {
  if (window.Whimbrel.DEMO_MODE) {
    return [{ tag_name: "v0.1.0", html_url: "#", assets: [
      { name: "guillemot-v0.1.0.zip", browser_download_url: "#" },
      { name: "uguisu-v0.1.0.zip", browser_download_url: "#" }
    ]}];
  }
  // ... real implementation
};
```

The asset names must match the prefix filter in `firmware.js` (`guillemot-` or `uguisu-`). A mismatch causes the release selector to show no asset and leaves Flash disabled.

### `js/app.js`

Destructure `DEMO_MODE` at the top of the IIFE:

```javascript
const { CONFIG, DEMO_MODE, generateKey, ... } = window.Whimbrel;
```

In `provisionDevice()`, add the bypass immediately after setting `keysProvisioningInProgress = true`:

```javascript
if (DEMO_MODE) {
  try {
    setStatus("Writing key…");
    await abortableDelay(600, () => keysProvisionAborted);
    if (keysProvisionAborted) { setStatus(""); return; }
    setStatus("Waiting for device to boot…");
    await abortableDelay(900, () => keysProvisionAborted);
    if (keysProvisionAborted) { setStatus(""); return; }
    setStatus("Done. Device provisioned and running.");
    if (deviceId === CONFIG.DEVICE_ID_FOB) {
      fobFlashed = true;
      keysProvisioningInPostCircle = true;
      await runTimeout(el.timeoutIndicator, el.progressCircle, 1500, () => keysProvisionAborted);
      keysProvisioningInPostCircle = false;
      if (!keysProvisionAborted) showStep(2);
    }
    if (deviceId === CONFIG.DEVICE_ID_RX) receiverFlashed = true;
    if (fobFlashed && receiverFlashed && currentStepIdx === 2) {
      await showStep(3);
      triggerConfetti();
    }
  } catch (e) {
    if (!keysProvisionAborted) setStatus(e.message || "Demo error", true);
  } finally {
    keysProvisioningInProgress = false;
  }
  return;
}
// ... real implementation follows
```

### `js/firmware.js`

Destructure `DEMO_MODE` at the top:

```javascript
const { CONFIG, DEMO_MODE, fetchDeviceReleases, ... } = window.Whimbrel;
```

In the Flash button click handler, add the bypass immediately after `fwFlashAborted = false`:

```javascript
if (DEMO_MODE) {
  try {
    setFwStatus("Downloading firmware package...", 0);
    await abortableDelay(400, () => fwFlashAborted);
    if (fwFlashAborted) return;
    setFwStatus("Parsing zip file...", 0.1);
    await abortableDelay(300, () => fwFlashAborted);
    if (fwFlashAborted) return;
    setFwStatus("Starting DFU process...", 0.2);
    for (let i = 1; i <= 10; i++) {
      if (fwFlashAborted) return;
      setFwStatus("Writing firmware...", 0.2 + (i / 10) * 0.8);
      await abortableDelay(200, () => fwFlashAborted);
    }
    if (fwFlashAborted) return;
    setFwStatusSuccessWithLink();
    triggerConfetti();
  } catch (e) {
    if (!fwFlashAborted) setFwStatus(`Error: ${e.message}`, null, true);
  } finally {
    fwFlashingInProgress = false;
  }
  return;
}
// ... real implementation follows
```

### `css/style.css`

Add the `.demo-badge` block. In main this doesn't exist, so it belongs only in demo. Place it near the header/tagline styles:

```css
.demo-badge {
  display: inline-block;
  margin-left: 0.5rem;
  padding: 0.15rem 0.5rem;
  font-size: 0.75rem;
  font-weight: 600;
  text-transform: uppercase;
  letter-spacing: 0.05em;
  color: var(--surface);
  background: var(--success);
  border-radius: 4px;
  vertical-align: middle;
}
```

---

## Step 3: Commit and Push

```bash
git add index.html js/config.js js/serial.js js/api.js js/app.js js/firmware.js css/style.css
git commit -m "Sync main into demo and re-enable demo flags"
git push origin demo
```

If a CSS fix was needed after the merge, commit that separately with a clear message explaining what was restored and why.

---

## Checklist

- [ ] `git checkout demo && git merge -X theirs main --no-edit`
- [ ] `git diff main -- css/style.css` — verify no rules from main are missing
- [ ] `index.html`: `window.WHIMBREL_DEMO = true` before `config.js`; demo badge in tagline
- [ ] `config.js`: `DEMO_MODE` constant
- [ ] `serial.js`: `isSupported()` bypass
- [ ] `api.js`: fake release with both `guillemot-` and `uguisu-` zip assets
- [ ] `app.js`: `DEMO_MODE` destructured; `provisionDevice()` bypass
- [ ] `firmware.js`: `DEMO_MODE` destructured; Flash button bypass
- [ ] `css/style.css`: `.demo-badge` block present
- [ ] Open the firmware dropdown in browser — items should be left-aligned with padding and a separator above the custom options
- [ ] Full flow test: Guillemot → DFU instructions → Flash (should animate and confetti)
- [ ] Full flow test: Keys tab → Generate → Flash Fob → Flash Receiver → All done
- [ ] No Web Serial permission dialog should appear anywhere
- [ ] Commit and push

---

*Last updated: March 2026 (after monorepo sync + CSS corruption fix)*

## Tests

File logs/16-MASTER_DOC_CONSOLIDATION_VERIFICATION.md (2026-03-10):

# Master Document Consolidation & Verification

*Date: 2026-03-10 01:28*

**Status:** COMPLETE — Master document deleted, all content verified in monorepo.

---

## Context

A standalone master document (`BLE_Immobilizer_G30_Detailed(10).md`) existed at the project root alongside the Immogen monorepo. This document contained system-level design specifications for the three-part immobilizer (Uguisu fob, Guillemot receiver, Whimbrel web app). To reduce maintenance burden and prevent documentation drift, a consolidation audit was performed to verify all content existed in the monorepo before deletion.

---

## Audit Scope

The master document covered eight major sections:

1. **Overview** — System architecture, deck placement, signal diagram
2. **BLE Protocol** — Advertisement-based messaging, 9-byte payload spec
3. **Uguisu (Key Fob)** — Hardware BOM (~$10), firmware boot flow, power budget
4. **Guillemot (Deck Receiver)** — Hardware specs, PCB layout, signal flow, BOM (~$25–30)
5. **Whimbrel (Provisioning App)** — Web Serial protocol, security model, key generation
6. **Build Notes** — Assembly, conformal coating, buzzer timing
7. **Design Notes** — Component rationale (AO3422, POR circuit, gate isolation, MOSFET selection, NVS wear)
8. **TBD** — Pending items (enclosure CAD, validation)

---

## Coverage Analysis

### Section-by-Section Mapping

| Master Section | Repo Location | Status | Notes |
|---|---|---|---|
| **Overview** | `README.md` § Overview | ✅ COMPLETE | Identical ASCII diagram and system description |
| **BLE Protocol** | `README.md` § BLE Protocol | ✅ COMPLETE | Updated with company ID offset spec |
| **Uguisu BOM** | `Uguisu/README.md` § Hardware | ✅ COMPLETE | Upgraded to 400 mAh LiPo + new switch/LED |
| **Uguisu firmware** | `Uguisu/README.md` § Software | ✅ COMPLETE | Detailed boot flow pseudocode (lines 76–109) |
| **Guillemot hardware/BOM** | `Guillemot/README.md` § Hardware | ✅ COMPLETE | Comprehensive BOM with all passives |
| **PCB layout specs** | `Guillemot/README.md` § PCB Layout | ✅ COMPLETE | All 6 critical specs present (GND jumper, clearance, RF keepout, etc.) |
| **Signal flow** | `Guillemot/README.md` § Operation | ✅ COMPLETE | Unlock/lock/power flows documented |
| **Design notes (7 items)** | `Guillemot/README.md` § Design Notes | ✅ COMPLETE | AO3422 rationale, POR circuit, gate isolation, MOSFET selection, all present |
| **NVS wear** | `Uguisu/README.md` § Design Notes | ✅ COMPLETE | 2.7 years / wear-leveling documented |
| **EasyEDA→KiCad** | Both READMEs | ✅ COMPLETE | Tool reference and usage present |
| **Whimbrel security** | `Guillemot/README.md` § Onboarding + `Uguisu/README.md` § Onboarding | ✅ COMPLETE | Write-only security, physical presence requirement documented |
| **Whimbrel ephemeral keys** | `Whimbrel/README.md` § Ephemeral Memory | ✅ COMPLETE | More detailed than master (includes device-replacement scenario) |
| **TBD items** | `README.md` § TBD | ✅ COMPLETE | Enclosure CAD + validation identical |

### Discrepancies & Corrections

The master document contained **outdated values** that have been corrected in the repo based on real measurement and analysis:

| Parameter | Master Doc | Repo Docs | Source |
|---|---|---|---|
| **Guillemot locked current** | ~22 μA | ~306 μA | `logs/15-BLE_POWER_ANALYSIS_AND_DOCUMENTATION_DISCREPANCY.md` |
| **Uguisu standby current** | < 5 μA | ~30 μA | Includes XIAO charging IC |
| **Uguisu per-press energy** | ~0.004 mAh | ~0.006 mAh | Real measurement via PPK2 |
| **Uguisu battery capacity** | 100 mAh | 400 mAh | Hardware upgrade (TW-502535 vs. generic) |
| **Guillemot scan duty cycle** | 20 ms / 2 s (1%) | 25 ms / 500 ms (5%) | Updated for better detection (see logs/8, logs/11) |

These corrections reflect iterative refinement through:
- Power analysis (logs/15)
- Architecture review & critique (logs/7)
- BLE timing simulation (logs/10)
- Build validation and real-world testing

### Minor Items Not in Repo

Three items appeared exclusively in the master document:

1. **Conformal coating instructions** — "Conformal coat PCB (exclude USB-C, XT60 joints, and buzzer port). Drill 3 mm acoustic port + mesh in scooter battery box for BZ1."
   - **Status:** Discarded. User opted not to conformal coat final build.

2. **QSPI flash sleep (0xB9)** — Firmware detail: `nrf_qspi_mem_object_read(0, sizeof(...))`; `nrf_qspi_mem_deep_power_down()`; `sd_power_system_off()`.
   - **Status:** Discarded. Not utilized in firmware; firmware code is authoritative.

3. **Whimbrel ephemeral session keys** — "Closing the tab permanently deletes the session key."
   - **Status:** Already in `Whimbrel/README.md` § Ephemeral Memory (lines 30–32), more comprehensive.

---

## Conclusion

✅ **All actionable content from the master document is present in the monorepo.**

The distributed documentation is **more accurate and comprehensive** than the master document:
- **Immogen/README.md** — System overview, repository structure, protocol spec
- **Immogen/Guillemot/README.md** — Receiver design, PCB layout, operation, design rationale
- **Immogen/Uguisu/README.md** — Fob design, GPIO mapping, LED behavior, boot flow
- **Whimbrel/README.md** — Provisioning protocol, security model, ephemeral key storage
- **Immogen/logs/** — 15+ technical deep-dives, architecture reviews, migration guides, power analysis

**Master document deleted:** 2026-03-10.

---

## Recommended Reading Order

For new contributors:

1. `Immogen/README.md` — Start here for system overview
2. `Immogen/Guillemot/README.md` — Receiver hardware & firmware
3. `Immogen/Uguisu/README.md` — Fob hardware & firmware
4. `Whimbrel/README.md` — Provisioning workflow
5. `Immogen/logs/2-CODEBASE_TECHNICAL_WRITEUP.md` — Deep technical reference
6. `Immogen/logs/15-BLE_POWER_ANALYSIS_AND_DOCUMENTATION_DISCREPANCY.md` — Power budget derivation

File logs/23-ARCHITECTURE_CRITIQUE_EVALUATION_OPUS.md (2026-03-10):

# Architecture Critique Evaluation

*Date: 2026-03-10 09:34*

Evaluation of every item from `21-ARCHITECTURE_CRITIQUE_COMBINED.md` against the actual codebase. Each item is rated: **Valid**, **Partially Valid**, **Wrong**, or **Misleading**.

---

## 1. LittleFS Power Drain — Valid, severity overstated

**Claimed problem:** On every button press, Uguisu linearly scans up to 512 CRC32-checked records from a 4KB LittleFS log just to read the last counter. Wastes milliseconds of CPU and flash power before BLE even starts.

**Evaluation:** Confirmed. `immo_storage.cpp:34-44` reads 8-byte records in a while loop. 4096 / 8 = 512 iterations max, each with `read()` + `crc32_ieee()`. However, CRC32 of 4 bytes is microseconds. The full scan is ~2-5ms total — not the power disaster described. The log only reaches 512 records after 512 button presses without rotation.

**Fix:** Add a `last_counter_` cache in a `.noinit` RAM section (survives `sd_power_system_off()`). On cold boot (battery insertion), scan LittleFS once and populate the cache. On subsequent wakes, read from RAM in microseconds.

```cpp
// In immo_storage.h — add retention cache
static uint32_t __attribute__((section(".noinit"))) s_cached_counter;
static uint32_t __attribute__((section(".noinit"))) s_cache_magic;
static constexpr uint32_t CACHE_VALID = 0xC0DE600D;

// In loadLast() — check cache first
uint32_t CounterStore::loadLast() {
  if (s_cache_magic == CACHE_VALID) {
    last_counter_ = s_cached_counter;
  } else {
    load();  // full scan on cold boot only
    s_cache_magic = CACHE_VALID;
  }
  s_cached_counter = last_counter_;
  return last_counter_;
}

// In update() — keep cache in sync
void CounterStore::update(uint32_t counter) {
  // ... existing write logic ...
  s_cached_counter = counter;
}
```

---

## 2. Button Press Timing Offset — Valid

**Claimed problem:** `wait_for_button_press_release()` runs after boot init (~100-200ms). The button press that woke the device is already in progress, so measured duration is shorter than actual. 1000ms long-press threshold effectively requires ~1200ms of physical holding.

**Evaluation:** Confirmed. Boot path before `wait_for_button_press_release()` at `Uguisu/main.cpp:107` includes `delay(50)`, LittleFS init, key load, and `Bluefruit.begin()`. The button is already LOW when the timing starts. Measured press is shorter than physical press by the boot time.

**Fix:** Record boot start time and compensate.

```cpp
// At top of setup()
const uint32_t boot_start = millis();

// When measuring press duration (line 107-110)
const uint32_t press_ms = wait_for_button_press_release(UGUISU_BUTTON_TIMEOUT_MS);
if (press_ms == 0) system_off();
const uint32_t compensated_ms = press_ms + (millis() - boot_start - press_ms);
// Simpler: just add boot overhead directly
const uint32_t total_ms = press_ms + boot_start;  // boot_start ≈ time spent in init
const immo::Command command =
    (total_ms >= UGUISU_LONG_PRESS_MS) ? immo::Command::Lock : immo::Command::Unlock;
```

Alternative simpler fix: just lower the threshold to 800ms to account for typical boot time.

---

## 3. Button Timeout Excessive — Valid, misleading framing

**Claimed problem:** 10 seconds awake at ~5mA waiting for a button press that already triggered the wake. 2-3 seconds is sufficient.

**Evaluation:** The 10s timeout (`uguisu_nrf52840.h:33`) only matters when the button is NOT pressed when code reaches the check (noise wake, or user released during boot). In normal operation, the button is already LOW and the code proceeds immediately to timing the release — the 10s is never reached. The framing suggests energy waste on every press, which doesn't happen.

**Fix:** Reduce to 2-3 seconds. Low-risk change, saves power only on accidental wakes.

```cpp
#define UGUISU_BUTTON_TIMEOUT_MS 2000
```

---

## 4. FreeRTOS LED Task Overkill — Valid, irrelevant in practice

**Claimed problem:** Spawns a FreeRTOS task with 512 bytes of stack just to blink a blue LED during provisioning.

**Evaluation:** Confirmed at `Uguisu/main.cpp:92`. But this only runs when USB-connected for provisioning — never during battery operation. Zero impact on battery life or production use. The 512 bytes is trivial on the nRF52840's 256KB RAM.

**Fix (if desired):** Replace with a FreeRTOS software timer.

```cpp
static TimerHandle_t g_prov_led_timer = nullptr;
static void prov_led_cb(TimerHandle_t) { led::prov_pulse_step(); }

// In setup(), replace xTaskCreate with:
g_prov_led_timer = xTimerCreate("prov", pdMS_TO_TICKS(30), pdTRUE, nullptr, prov_led_cb);
xTimerStart(g_prov_led_timer, 0);

// Cleanup: xTimerDelete(g_prov_led_timer, 0);
```

Requires refactoring `led::prov_pulse()` into a non-blocking step function. Low priority.

---

## 5. Blocking the BLE Stack — Valid, low practical impact

**Claimed problem:** `handle_valid_command()` plays buzzer tones using blocking `delay()` inside `scan_callback`, stalling the BLE scanner for ~260ms.

**Evaluation:** Confirmed. `Guillemot/main.cpp:34-38` uses `delay(duration_ms)`. Two tones (130ms each) + latch pulse (15ms) = ~275ms blocking inside the radio callback. However: the fob sends ~30 duplicate packets over 600ms. Only one needs to arrive before the block. Subsequent duplicates are harmless (counter already accepted). Single-fob system.

**Fix:** Decouple actuation from the BLE callback via a FreeRTOS queue.

```cpp
static QueueHandle_t g_cmd_queue;

// In scan_callback: push payload instead of acting
void scan_callback(ble_gap_evt_adv_report_t* report) {
  immo::Payload pl{};
  if (!parse_payload_from_report(report, pl)) return;
  if (key_is_all_zeros()) return;
  if (!verify_payload(pl)) return;
  xQueueSend(g_cmd_queue, &pl, 0);  // non-blocking
}

// Dedicated task consumes queue
void immo_task(void*) {
  immo::Payload pl;
  for (;;) {
    if (xQueueReceive(g_cmd_queue, &pl, portMAX_DELAY)) {
      handle_valid_command(pl);
    }
  }
}

// In setup():
g_cmd_queue = xQueueCreate(2, sizeof(immo::Payload));
xTaskCreate(immo_task, "immo", 256, nullptr, 1, nullptr);
```

---

## 6. Continuous 5% Duty Cycle — Valid, non-issue

**Claimed problem:** 25ms/500ms scan draws ~250µA average, a constant vampire drain on the scooter battery.

**Evaluation:** Confirmed. But at 250µA on a 15Ah battery: 6mAh/day = 0.04% per day. The scooter would need to sit for ~7 years to drain from scanning alone. Gemini acknowledges this is "acceptable."

**Fix:** Not needed. The current duty cycle is already well-optimized for latency vs. power.

---

## 7. No Watchdog on Guillemot — Valid, CRITICAL

**Claimed problem:** No WDT configured. If firmware hangs (SoftDevice error, flash corruption, radio lockup), the scooter stays in whatever state it was in — potentially unlocked indefinitely.

**Evaluation:** Confirmed. No WDT configuration anywhere in the Guillemot codebase. `loop()` at line 137 is just `sd_app_evt_wait()`. If events stop arriving, the loop sleeps forever. The SR latch holds its last state. This is the most important finding in the entire review.

**Fix:** Configure the nRF52840 WDT. The SoftDevice supports WDT coexistence.

```cpp
#include <nrf_wdt.h>

static nrf_drv_wdt_channel_id g_wdt_channel;

void wdt_event_handler(void) {
  // On WDT timeout: system resets. Latch stays in current state.
  // After reboot, Guillemot re-enters locked scanning mode.
}

// In setup(), after Bluefruit.Scanner.start():
nrf_drv_wdt_config_t config = NRF_DRV_WDT_DEAFULT_CONFIG;
config.reload_value = 8000;  // 8 second timeout
nrf_drv_wdt_init(&config, wdt_event_handler);
nrf_drv_wdt_channel_alloc(&g_wdt_channel);
nrf_drv_wdt_enable();

// In loop() or scan_callback:
nrf_drv_wdt_channel_feed(g_wdt_channel);
```

The WDT must be fed from the main loop or a timer. If `sd_app_evt_wait()` returns events normally, the WDT gets fed. If the system locks up, the WDT resets the MCU after 8 seconds, re-entering the locked scanning state.

---

## 8. `ccm_mic_8()` Return Value Unchecked — WRONG

**Claimed problem:** `verify_payload()` may not check the return value of `ccm_mic_8()`, potentially comparing against an uninitialized buffer.

**Evaluation:** The return value IS checked. `Guillemot/main.cpp:63-64`:

```cpp
if (!immo::ccm_mic_8(g_psk, nonce, msg, sizeof(msg), expected)) return false;
```

The payload is rejected immediately on failure. The reviewer either examined an older version or missed this line.

**Fix:** None needed. Code is already correct.

---

## 9. Nonce Lacks Session Diversifier — Valid, low practical risk

**Claimed problem:** Nonce is `LE32(counter) || 0x00×9`. If the same key is re-provisioned with a counter reset, nonce reuse breaks CCM.

**Evaluation:** Confirmed at `immo_crypto.cpp:35-38`. The 9 zero bytes are wasted. However, Whimbrel generates a new random key each provisioning, so the same (key, nonce) pair only recurs if someone deliberately provisions the same key twice. Low practical risk.

**Fix:** Generate a random 4-byte session ID during provisioning. Store alongside the key. Include in nonce bytes 4-7.

```cpp
// immo_crypto.cpp
void build_nonce(uint32_t counter, const uint8_t session_id[4], uint8_t nonce[NONCE_LEN]) {
  le32_write(&nonce[0], counter);
  memcpy(&nonce[4], session_id, 4);
  for (size_t i = 8; i < NONCE_LEN; i++) nonce[i] = 0;
}
```

Requires adding session_id to the provisioning payload format and storage. Both fob and receiver must agree on it.

---

## 10. Payload Authenticated but Not Encrypted — Valid

**Claimed problem:** Counter and command are sent in plaintext. A passive sniffer sees lock/unlock commands and counter values (usage frequency). Full CCM encryption is nearly free.

**Evaluation:** Confirmed. `Uguisu/main.cpp:128-129` copies plaintext `msg` into the payload. `ccm_mic_8()` only computes the CBC-MAC tag, not the CTR-mode keystream for encryption. A sniffer sees which command was sent and the counter value. However, this doesn't enable attacks — you can't forge a MIC without the key.

**Fix:** Extend `ccm_mic_8()` to also produce the CTR-mode keystream and XOR it with the plaintext. Rename to `ccm_encrypt_8()`.

```cpp
// After computing the MIC (existing code), add CTR encryption:
// Generate keystream blocks A1, A2, ... and XOR with plaintext
for (uint16_t ctr_i = 1; offset_enc < msg_len; ctr_i++) {
  uint8_t ai[16]{};
  ai[0] = static_cast<uint8_t>(L - 1);
  memcpy(&ai[1], nonce, NONCE_LEN);
  ai[14] = static_cast<uint8_t>((ctr_i >> 8) & 0xFF);
  ai[15] = static_cast<uint8_t>(ctr_i & 0xFF);

  uint8_t si[16]{};
  if (!aes128_ecb_encrypt(key, ai, si)) return false;

  const size_t n = min((size_t)16, msg_len - offset_enc);
  for (size_t j = 0; j < n; j++)
    out_ct[offset_enc + j] = msg[offset_enc + j] ^ si[j];
  offset_enc += n;
}
```

Requires corresponding decryption on the receiver side before MIC verification. Cost: one additional AES block (5-byte message fits in one block).

---

## 11. Manual CCM Instead of Hardware NRF_CCM — MISLEADING

**Claimed problem:** The code manually implements CCM via ECB loops. The nRF52840 has a hardware NRF_CCM peripheral that should be used instead.

**Evaluation:** The nRF52840 SoftDevice (S140) **reserves the CCM, AAR, and ECB peripherals for its own use**. Direct access to `NRF_CCM` is blocked. The only crypto API available to application code is `sd_ecb_block_encrypt()`, which is exactly what the code uses. There is no higher-level SoftDevice CCM API for application use. The manual ECB-based CCM implementation is the standard and correct approach on nRF52 with SoftDevice.

**Fix:** None needed. The code is already doing the only thing possible without ditching the SoftDevice.

---

## 12. Counter Log Rotation Power-Failure Bug — Valid, SECURITY BUG

**Claimed problem:** `rotateIfNeeded_()` does `remove(old)` → `rename(current → old)`. If power fails after the rename but before `update()` writes to the new log, `load()` reads the current log (doesn't exist), sets `last_counter_ = 0`, and never reads the old log. Counter resets, enabling replay.

**Evaluation:** Confirmed. `immo_storage.cpp:73-81`: after rotation, `log_path_` doesn't exist. `load()` at line 34-44 only opens `log_path_`. It never reads `old_log_path_`. If `log_path_` doesn't exist, `last_counter_` stays 0. Both Uguisu and Guillemot share this code and are vulnerable.

**Fix:** Scan both files in `load()`, take the maximum.

```cpp
void CounterStore::load() {
  last_counter_ = 0;
  scan_file_(log_path_);
  scan_file_(old_log_path_);
}

void CounterStore::scan_file_(const char* path) {
  Adafruit_LittleFS_Namespace::File f(InternalFS.open(path, Adafruit_LittleFS_Namespace::FILE_O_READ));
  if (!f) return;

  CounterRecord rec{};
  while (f.read(reinterpret_cast<void*>(&rec), sizeof(rec)) == sizeof(rec)) {
    if (record_crc(rec.counter) != rec.crc32) continue;
    if (rec.counter > last_counter_) last_counter_ = rec.counter;
  }
}
```

Add `void scan_file_(const char* path);` to the private section of `CounterStore` in the header.

---

## 13. No Delivery Confirmation — Valid, inherent tradeoff

**Claimed problem:** Fob broadcasts for 600ms and sleeps with no acknowledgment. User gets zero feedback if out of range.

**Evaluation:** Confirmed. The LED on the fob confirms "I sent it," not "they got it." However, adding confirmation requires a connection or back-channel scanner, which would dramatically increase power consumption and complexity. Most car key fobs have the same limitation. This is a deliberate architectural tradeoff, not an oversight.

**Fix:** If desired, add a brief scanner on the fob to listen for an ACK advertisement from Guillemot. Cost: ~50-100ms additional active time per press, plus code on both sides. Probably not worth the complexity for a scooter fob.

---

## 14. Company ID 0xFFFF — Partially valid

**Claimed problem:** 0xFFFF is the BT SIG test/unregistered ID. Other devices using it trigger full MIC checks before rejection.

**Evaluation:** `guillemot_nrf52840.h:14` confirms `MSD_COMPANY_ID = 0xFFFF`. But `Guillemot/main.cpp:128` calls `Bluefruit.Scanner.filterMSD(MSD_COMPANY_ID)`, which filters at the radio level. Only matching advertisements trigger the callback. Random 0xFFFF devices in the wild are rare. For production, a registered ID is proper. For prototyping, fine.

**Fix:** For production, either register a Bluetooth SIG company ID ($7,500/year) or add a magic-byte prefix to the MSD payload for cheaper filtering:

```cpp
// Add 2-byte magic after company ID
static constexpr uint16_t IMMOGEN_MAGIC = 0x494D;  // "IM"

// In parse_payload_from_report: check magic before parsing
if (msd[2] != (IMMOGEN_MAGIC & 0xFF) || msd[3] != (IMMOGEN_MAGIC >> 8)) return false;
```

Increases MSD size by 2 bytes (15 → 17), still within BLE limits.

---

## 15-17. Hardware Documentation Errors — Very likely valid

**Claimed problem:** The technical documentation (`18-CODEBASE_TECHNICAL_DOCUMENTATION.md`) misrepresents the Guillemot PCB in three ways:

1. **MOSFET topology:** Doc shows `Drain ← +BATT, Source → ESC-` (high-side N-FET). An N-FET high-side switch with 42V on the source needs Vg > 46V to turn on. The 10V gate drive can't do this. The actual design must be a low-side switch (Drain ← ESC-, Source → GND, Vgs = 10V).

2. **10V rail purpose:** Doc describes Q3 (P-FET) as a "bleeder" and D2's 10V Zener as being "on the regulated rail." Gemini claims Q3 actually switches +BATT through a Zener to create a 10V gate-drive rail for Q1, with zero quiescent draw when locked.

3. **P-FET gate protection:** Doc doesn't explain how Q3 survives with Source at 42V. Without clamping, Vgs could reach -42V, exceeding the SI2309CDS's -20V max. D1 (12V Zener) must be clamping Vgs, but the doc says D1 "clamps buck input."

**Evaluation:** Cannot verify directly against the KiCad binary schematic, but the electrical arguments are sound. The documented topology is electrically impossible as described. The 10V gate drive only works for a low-side switch.

**Fix:** Rewrite Section 6 of `18-CODEBASE_TECHNICAL_DOCUMENTATION.md`. The signal flow diagram should show:

```
Q1 (IPB042N10N3G) — LOW-SIDE SWITCH:
  Drain ← ESC- (load return path)
  Source → GND (battery negative)
  Gate  ← ISO_GATE (10V when unlocked, 0V when locked)

Q3 (SI2309CDS) — 10V GATE DRIVE SWITCH:
  Source ← +BATT
  Drain  → R5 + D2 (10V Zener) → 10V_RAIL → Q1 gate
  Gate   ← D1 (12V Zener clamp) ← Q4 (2N7002) ← Q_UNLOCK
  Purpose: Switches battery through Zener regulator to create 10V gate drive.
           Zero quiescent current when locked (Q3 off, no current path).

D1 (BZT52C12-7-F) — GATE PROTECTION:
  Clamps Q3 Vgs to -12V (within SI2309CDS -20V abs max).
  NOT for "clamping buck input."
```

Verify these connections against the actual KiCad schematic before committing.

---

## 18. Hardware Design Issues — Valid, production hardening

**Claimed problem:** Five hardware issues identified: no reverse polarity protection, TVS overshoot, dual-NPN buzzer driver, no ESD protection, no conformal coating.

**Evaluation:** All are legitimate engineering concerns for a production design. None are showstoppers for a prototype.

**Fixes:**

- **Reverse polarity:** Add a P-FET ideal diode or Schottky on +BATT input. Schottky (e.g., SS54) is simplest; P-FET (e.g., SI2301) gives lower drop.
- **TVS overshoot:** Verify D1 Zener can handle the transient current during a TVS clamp event. If not, upsize D1 or add a second TVS stage.
- **Buzzer driver:** Replace high-side Q5 (NPN) with a PNP (e.g., MMBT3906). Or simplify to a single low-side N-FET.
- **ESD protection:** Add PESD5V0S2BT or similar on D0, D1, D3 lines.
- **Conformal coating:** Specify in production documentation. MG Chemicals 419D or similar.

All are schematic/BOM changes. No firmware modifications needed.

---

## 19. Extremely Short Button Presses (< 200ms) — Valid, missed UX edge case

**Claimed problem (User):** What happens if the user presses the button too short (shorter than 200ms)? The device wakes up but might miss the press. Can we make it unlock in that scenario?

**Evaluation:** Very valid. When the fob wakes from `system_off`, the boot process takes ~100-200ms. If the user releases the button before `wait_for_button_press_release()` starts, the pin is already HIGH. The function's first `while` loop will then sit there for 10 seconds waiting for a *new* press, eventually timing out and sleeping. The quick press is completely ignored.

**Fix:** Since the only wake source from `system_off` is the button, we *know* a press occurred if we just booted. If the button is already HIGH when we check it, we can immediately return a small duration (e.g., 1ms) to trigger an immediate Unlock, rather than waiting 10 seconds.

```cpp
// In wait_for_button_press_release(), after initial boot:
if (digitalRead(UGUISU_PIN_BUTTON) != LOW) {
  // Pin already HIGH. We woke from sleep but user already released.
  // Treat as a very short press (Unlock).
  return 1; 
}
```

---

## 20. Early Exit on Long Press (> 1s) — Valid, UX improvement

**Claimed problem (User):** What happens if the user presses the button too long? Can we just set a timeout once it hits 1 sec and proceed to locking without waiting for release?

**Evaluation:** Valid. Currently, `wait_for_button_press_release()` blocks until the user *releases* the button, up to the 10-second timeout. If the user holds the button for 3 seconds, they get zero LED feedback until they let go. Waiting for release is unnecessary once the 1000ms `UGUISU_LONG_PRESS_MS` threshold is crossed.

**Fix:** Break out of the polling loop immediately once the duration exceeds the long-press threshold. This provides instant LED feedback exactly at 1 second, making the fob feel much more responsive.

```cpp
const uint32_t press_start = millis();
while (millis() < deadline && digitalRead(UGUISU_PIN_BUTTON) == LOW) {
  if (millis() - press_start >= UGUISU_LONG_PRESS_MS) {
    // Threshold reached, no need to wait for release
    return UGUISU_LONG_PRESS_MS; 
  }
  delay(10);
}
return millis() - press_start;
```

---

## Priority Summary

| Priority | Item | Action |
|---|---|---|
| **P0** | #7 No watchdog | Add WDT to Guillemot immediately |
| **P0** | #12 Rotation power-failure bug | Fix `load()` to scan both files |
| **P1** | #15-17 Hardware doc errors | Rewrite Section 6 of technical docs |
| **P2** | #10 No encryption | Add CTR-mode encryption to CCM |
| **P2** | #2 Button timing offset | Compensate or lower threshold |
| **P2** | #18 Hardware hardening | Address for production revision |
| **P2** | #19 Short press missed | Fix `wait_for_button_press_release` to assume Unlock if already HIGH |
| **P2** | #20 Long press delayed UX | Early exit from polling loop at 1000ms |
| **P3** | #1 LittleFS cache | Add noinit RAM cache |
| **P3** | #5 BLE blocking | Decouple with FreeRTOS queue |
| **P3** | #9 Nonce diversifier | Add session ID to provisioning |
| **P3** | #14 Company ID | Add magic prefix or register ID |
| Skip | #3 Button timeout | Trivial config change if desired |
| Skip | #4 FreeRTOS LED task | No real-world impact |
| Skip | #6 Duty cycle | Non-issue on scooter battery |
| N/A | #8 Return value check | Already correct, no action |
| N/A | #11 Hardware CCM | Not possible with SoftDevice |
| N/A | #13 Delivery confirmation | Architectural tradeoff, not a bug |

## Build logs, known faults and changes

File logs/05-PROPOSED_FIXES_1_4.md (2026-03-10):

# Proposed Fixes 1–4: Revised Implementations

*Date: 2026-03-09 06:35*

*Fixes derived from CODEBASE_REVIEW_FINDINGS.md, rewritten against actual source.*

---

## Fix 1 — Reject Commands When Unprovisioned (HIGH)

### Problem

When Guillemot has never been provisioned, `g_psk` is all zeros (loaded from
`k_default_psk` by `load_psk_from_storage`). An attacker who knows the system
uses AES-CCM with a zero key can craft a valid MIC for any counter/command pair.
`verify_payload` will pass because it computes the MAC with the same zero key.

### Why it matters

The zero-key state is deterministic and public (it's a hardcoded constant in
source). Any attacker who reads the firmware or knows the protocol can unlock
the immobilizer on an unprovisioned device.

### Fix

`key_is_all_zeros()` already exists at line 54 of `guillemot/src/main.cpp`.
It is currently only used as the `is_provisioned` callback for
`ensure_provisioned`. The fix is a one-line addition to `scan_callback`:

```cpp
// guillemot/src/main.cpp, lines 151-156
void scan_callback(ble_gap_evt_adv_report_t* report) {
  immo::Payload pl{};
  if (!parse_payload_from_report(report, pl)) return;
  if (key_is_all_zeros()) return;          // <-- ADD THIS LINE
  if (!verify_payload(pl)) return;
  handle_valid_command(pl);
}
```

This reuses the existing function with zero new code. The guard sits before
`verify_payload` so we never even attempt cryptographic verification with a
known-bad key.

### Tradeoff

None. An unprovisioned device has no legitimate fob paired to it, so rejecting
all commands is correct behavior.

---

## Fix 2 — Persist Counter Before Advertising on Uguisu (HIGH)

### Problem

In `uguisu/src/main.cpp` lines 191–194, the current order is:

```
start_advertising_once(...)   // line 191 — begin BLE broadcast
delay(UGUISU_ADVERTISE_MS)    // line 192 — wait for receiver to pick it up
g_store.update(counter)       // line 193 — persist incremented counter
system_off()                  // line 194 — deep sleep
```

If power is lost during the `delay` window (battery dies, user pulls battery,
voltage sag), the counter is never persisted. On next boot, `loadLast()` returns
the same value, the fob reuses the same counter, and the signed payload is
identical — a replay. Guillemot will accept it because `pl.counter > last` still
holds (the receiver saw it and persisted, but the fob didn't).

Worse: if the receiver *also* lost power (both devices on the scooter), the
receiver's counter is also stale, and the replayed payload works again. But even
if only the fob loses power, the fob is now stuck — it will keep generating the
same counter that Guillemot already consumed and will reject.

### Fix

Move `g_store.update(counter)` before the advertising call:

```cpp
// uguisu/src/main.cpp, lines 191-194 become:
g_store.update(counter);                        // persist FIRST
start_advertising_once(MSD_COMPANY_ID, payload13);
delay(UGUISU_ADVERTISE_MS);
system_off();
```

### Tradeoff

If `update()` succeeds but advertising fails (BLE stack error, immediate power
loss before any packet transmitted), the counter is advanced but no command
was delivered. The fob "wastes" one counter value. This is harmless — the user
presses the button again, gets counter+2, and everything works. Counter space
is 2^32, so wasting values is not a concern.

The alternative (counter reuse / replay) is a security and reliability failure.
Wasting a counter value is strictly better.

---

## Fix 3 — Persist Counter Before Actuation on Guillemot (MEDIUM)

### Problem

In `guillemot/src/main.cpp` `handle_valid_command` (lines 130–148):

```cpp
case immo::Command::Unlock:
  latch_set_pulse();                 // physical action — 15ms pulse
  buzzer_tone_ms(BUZZER_UNLOCK_MS);  // blocking buzzer — hundreds of ms
  g_store.update(pl.counter);        // persist counter AFTER
  break;
```

If power is lost after `latch_set_pulse` but before `g_store.update`, the
latch has physically moved (scooter unlocked) but the counter is not persisted.
On next boot, `lastCounter()` returns the old value. The same signed payload
from the fob would be accepted again — but the fob has already advanced its own
counter past this value (assuming fix 2), so the real consequence is:

- The receiver's counter is behind the fob's counter.
- The next legitimate fob press (counter N+1) will still work because N+1 > old.
- But if an attacker captured the BLE advertisement for counter N, they can
  replay it after the power loss because the receiver thinks N is still fresh.

This is a narrower window than fix 2, but `buzzer_tone_ms` blocks for the full
buzzer duration (likely 100–500ms), which is a meaningful power-loss window.

### Fix

Persist counter first, then actuate:

```cpp
void handle_valid_command(const immo::Payload& pl) {
  const uint32_t last = g_store.lastCounter();
  if (pl.counter <= last) return;

  // Persist counter BEFORE physical action
  g_store.update(pl.counter);

  switch (pl.command) {
    case immo::Command::Unlock:
      latch_set_pulse();
      buzzer_tone_ms(BUZZER_UNLOCK_MS);
      break;
    case immo::Command::Lock:
      buzzer_tone_ms(BUZZER_LOCK_MS);
      latch_reset_pulse();
      break;
    default:
      break;
  }
}
```

Note: `g_store.update()` is moved above the switch and called once,
eliminating the duplicated call in each case branch.

### Tradeoff

If `update()` succeeds but power dies before `latch_set_pulse`, the counter is
consumed but the latch didn't move. The user presses the fob again (next
counter), and it works. Same "wasted counter" tradeoff as fix 2 — acceptable.

If `update()` itself fails (flash write error), the function still proceeds
to actuate. Whether this is acceptable depends on your failure philosophy:

- **Option A (current approach above):** Actuate anyway. The device responds
  to the user even if storage is degraded. Risk: counter not persisted, replay
  possible on that one value.
- **Option B (strict):** Check `update()` return value, abort if it fails.
  Requires changing `update()` to return `bool`. Safer but means the device
  stops responding when flash is unhealthy.

I recommend Option A for now (matches current behavior, doesn't require API
changes), with a future enhancement to add a return value to `update()`.

---

## Fix 4 — Exact Checksum Length in Provisioning Parser (MEDIUM)

### Problem

In `immo_provisioning.cpp` line 86:

```cpp
if ((size_t)(col1 - key_hex) != 32 || (size_t)(col2 - counter_hex) != 8 || strlen(checksum_hex) < 4) {
```

`strlen(checksum_hex) < 4` accepts any checksum field of 4 or more characters.
Only the first 4 hex characters are consumed by `hex_byte` calls on lines
104–108. Trailing characters are silently ignored.

This means `PROV:...:...:ABCDgarbage` and `PROV:...:...:ABCD` are treated
identically. While not directly exploitable (the CRC still has to match the
key), it violates the principle of strict parsing: accept exactly what you
expect, reject everything else. Loose parsing invites confusion and makes
protocol evolution harder.

### Fix

Change `<` to `!=`:

```cpp
// immo_provisioning.cpp, line 86
if ((size_t)(col1 - key_hex) != 32 || (size_t)(col2 - counter_hex) != 8 || strlen(checksum_hex) != 4) {
```

That's it. One character change: `<` → `!=`.

The `hex_byte` calls on lines 104–108 already validate that the 4 characters
are valid hex digits (returning false on invalid nibbles), so no additional
hex validation loop is needed.

### Why not a bigger change

The original writeup proposed a 15-line replacement with explicit hex character
validation and restructured field-length checks. This is unnecessary because:

1. Field lengths for key (32) and counter (8) are already validated on the same
   line — no change needed.
2. `hex_byte()` (lines 7–18) already rejects non-hex characters by returning
   `false`, which triggers `ERR:MALFORMED` on lines 106–108.
3. The only actual gap is `< 4` vs `!= 4` for the checksum field.

### File note

This fix applies to `ImmoCommon/src/immo_provisioning.cpp`. If Guillemot and
Uguisu have vendored copies under `lib/ImmoCommon/`, the same one-character
change should be mirrored there.

---

## Summary

| Fix | Severity | Change size | Risk |
|-----|---|---|---|
| 1. Reject unprovisioned commands | HIGH | +1 line | None |
| 2. Uguisu persist-before-advertise | HIGH | Reorder 2 lines | Wasted counter on failed advert (harmless) |
| 3. Guillemot persist-before-actuate | MEDIUM | Move + deduplicate `update()` | Wasted counter on failed actuation (harmless) |
| 4. Strict checksum length | MEDIUM | 1 char change | None |

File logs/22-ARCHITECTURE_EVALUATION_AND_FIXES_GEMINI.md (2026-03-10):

# Immogen Architecture Evaluation & Fix Plan

*Date: 2026-03-10 09:14*

This document evaluates the architectural critiques from the combined review (`21-ARCHITECTURE_CRITIQUE_COMBINED.md`), filters out invalid claims, and outlines actionable fixes for the valid issues.

## 1. Uguisu (Key Fob) Firmware

### The LittleFS Power Drain
*   **Problem:** On every wake from `system_off`, `immo_storage::load()` sequentially reads the entire LittleFS counter log to find the latest anti-replay counter, wasting CPU cycles and battery.
*   **Validity:** **Valid.** `immo_storage.cpp` uses a linear `while (f.read(...))` loop. Since the fob restarts from deep sleep on every press, this linear scan happens on every use.
*   **Fix:** Utilize nRF52 General Purpose Retention Registers (`GPREGRET`) or `.noinit` RAM to cache the counter across `system_off` sleeps. Only scan LittleFS on a cold boot (battery insertion). Alternatively, use a raw flash page with a binary search instead of a full filesystem.

### Button Press Timing Offset
*   **Problem:** `wait_for_button_press_release()` runs after boot initialization (~100-200 ms). The physical press is longer than the measured press, making the 1000 ms long-press threshold effectively ~1200 ms.
*   **Validity:** **Valid.** The nRF52 wakes from `system_off()` with a reset. `setup()` takes time before polling the button.
*   **Fix:** Subtract an estimated boot time offset (e.g., 150 ms) from the duration calculated in `wait_for_button_press_release()`, or simply document the true physical threshold for users.

### Excessive Button Timeout
*   **Problem:** The 10-second wait for button release (`UGUISU_BUTTON_TIMEOUT_MS`) drains battery unnecessarily if a button is accidentally held down in a pocket.
*   **Validity:** **Valid.** The system stays awake drawing ~5 mA for up to 10 seconds.
*   **Fix:** Reduce `UGUISU_BUTTON_TIMEOUT_MS` from 10000 to 2000-3000 ms.

### Overkill FreeRTOS Task for Provisioning LED
*   **Problem:** Uguisu spawns a dedicated FreeRTOS task with a 512-byte stack just to blink a blue LED during USB provisioning.
*   **Validity:** **Valid.** While `ensure_provisioned()` blocks the main loop reading serial, an entire FreeRTOS task for an LED is heavy.
*   **Fix:** Use a non-blocking hardware timer/interrupt approach, or simply accept the minor overhead since it only occurs when plugged into USB power.

## 2. Guillemot (Receiver) Firmware

### Blocking the BLE Stack
*   **Problem:** `handle_valid_command()` blocks for hundreds of milliseconds using `buzzer_tone_ms()` (which uses `delay()`) from within the Bluefruit `scan_callback`.
*   **Validity:** **Valid.** `scan_callback` runs in a high-priority context. Blocking it stalls the BLE scanner, causing dropped packets.
*   **Fix:** Decouple actuation. Have `scan_callback` push valid commands to a FreeRTOS queue. A dedicated `ImmoTask` should consume the queue and handle latch/buzzer timing asynchronously.

### Missing Watchdog Timer (WDT)
*   **Problem:** Guillemot is an always-on safety device. If the firmware hangs, it stays in its current state forever.
*   **Validity:** **Valid.** No WDT is initialized in `Guillemot/firmware/src/main.cpp`.
*   **Fix:** Enable the nRF52840 hardware WDT with a suitable timeout (e.g., 5 seconds) and pet it in the idle loop or a dedicated task.

## 3. Cryptography & Security

### `verify_payload()` Not Checking `ccm_mic_8()` Return Value
*   **Problem:** Claimed that `verify_payload()` ignores the return value of `ccm_mic_8()`, potentially comparing against an uninitialized buffer if the SoftDevice ECB call fails.
*   **Validity:** **INVALID (BULLSHIT).** The codebase explicitly checks the return value in `Guillemot/firmware/src/main.cpp` line 64: `if (!immo::ccm_mic_8(g_psk, nonce, msg, sizeof(msg), expected)) return false;`. This claim is completely false and has been discarded.

### Missing Session Diversifier in Nonce
*   **Problem:** The CCM nonce pads 9 bytes with zeros. If a key is reused but the counter resets, the nonce repeats, breaking AES-CCM security.
*   **Validity:** **Valid.**
*   **Fix:** Generate 9 random bytes during the USB provisioning process, store them alongside the 16-byte key, and use them as the nonce suffix instead of zeros.

### Unencrypted Payload
*   **Problem:** The command and counter are sent in plaintext. An eavesdropper can see usage frequency and lock/unlock actions.
*   **Validity:** **Valid.** The implementation only uses CCM for authentication (CBC-MAC), not confidentiality.
*   **Fix:** Apply the CCM keystream to encrypt the 5-byte payload.

### Manual CCM vs. Hardware/SoftDevice
*   **Problem:** The crypto implementation manually loops ECB blocks instead of using the nRF52's hardware CCM or SoftDevice CCM API.
*   **Validity:** **Valid.** `immo_crypto.cpp` does manual CBC-MAC and CTR mode using `sd_ecb_block_encrypt()`.
*   **Fix:** Migrate to `sd_ble_opt_set` or `NRF_CCM` hardware peripheral to reduce active CPU time and manual cryptographic code.

## 4. Anti-Replay & Storage

### Power-Failure Vulnerability in Log Rotation
*   **Problem:** `rotateIfNeeded_()` renames `log` to `old_log`. If power fails before the new `log` is written, `load()` finds no `log` file and resets the counter to 0, opening a massive replay vulnerability.
*   **Validity:** **Valid.** `immo_storage.cpp`'s `load()` function only opens `log_path_`. It never checks `old_log_path_` if the primary log is missing.
*   **Fix:** Modify `load()` to read *both* `log_path_` and `old_log_path_`, taking the maximum valid counter found across both files.

## 5. BLE Protocol

### Unregistered Company ID 0xFFFF
*   **Problem:** 0xFFFF triggers unnecessary MIC verification attempts for any unregistered BLE device nearby.
*   **Validity:** **Valid.**
*   **Fix:** Assign a unique random 16-bit identifier or use a magic byte sequence in the payload to filter out non-Immogen advertisements early.

### No Delivery Confirmation
*   **Problem:** Fob has no way of knowing if the receiver actually heard the command.
*   **Validity:** **Valid, but accepted limitation.**
*   **Fix:** Implementing two-way communication requires the fob to switch to scanning mode, which adds latency and power draw. The scooter's buzzer provides auditory confirmation. This may be left as-is to preserve battery.

## 6. Hardware & Documentation

### Hardware Documentation Errors
*   **Problem:** The technical documentation misrepresents the Guillemot schematic (e.g., calling Q1 a high-side switch instead of low-side, misunderstanding the 10V gate drive and Vgs clamping).
*   **Validity:** **Valid.** The schematic uses a low-side N-FET (IPB042N10N3G) with the source tied to ESC- (GND return), and the 10V rail is indeed used to drive the gate.
*   **Fix:** Rewrite Section 6 of `18-CODEBASE_TECHNICAL_DOCUMENTATION.md` to accurately reflect the schematic topology.

### Missing Hardware Protections (Guillemot)
*   **Problem:** Missing reverse polarity protection, potential TVS overvoltage on buck, sub-optimal NPN push-pull, lack of ESD protection.
*   **Validity:** **Valid.**
*   **Fix:** Update the KiCad design in a future hardware revision (e.g., add a P-FET ideal diode, use a complementary NPN/PNP pair for the buzzer, add ESD TVS arrays on exposed GPIOs).

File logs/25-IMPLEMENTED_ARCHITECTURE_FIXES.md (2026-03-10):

# Architecture Fixes Summary

*Date: 2026-03-10 10:06*

This document summarizes the architectural issues identified during the system evaluation, outlining what the issues were, why they were problematic, and how we decided to address or skip them.

## Part 1: Implemented Fixes

### 1. Hardware Documentation Inaccuracies
- **What was the issue:** The technical documentation (`18-CODEBASE_TECHNICAL_DOCUMENTATION.md`) misrepresented the Guillemot PCB's MOSFET topology, 10V rail purpose, and P-FET gate protection.
- **Why it was an issue:** The documented design was electrically impossible (e.g., describing a 10V gate drive turning on a high-side N-FET with a 42V source, which would require Vg > 46V).
- **How we fixed it:** We created `24-HARDWARE_DOCUMENTATION_CORRECTIONS.md` to correctly describe the actual design: a low-side load switch topology, a 10V gate drive derived from the battery, and a 12V Zener clamping the gate-source voltage for protection.

### 2. Button Timing & UX Limitations
- **What was the issue:** Boot time (~100-200ms) caused the measured button press duration to be shorter than the physical press. Extremely short presses (< 200ms) were ignored, long presses provided no LED feedback until release, and the timeout was excessively long (10 seconds).
- **Why it was an issue:** It created a sluggish and unpredictable user experience, with delayed feedback or missed commands.
- **How we fixed it:** 
  - Reduced the long-press threshold to 700ms and the timeout to 2000ms.
  - Updated `wait_for_button_press_release()` to instantly return a short duration if the button pin is already HIGH after boot (capturing <200ms presses).
  - Implemented an early exit from the polling loop once the duration reaches 700ms, providing instant LED feedback exactly when the long-press threshold is met.

### 3. Log Rotation Power-Failure Vulnerability
- **What was the issue:** The LittleFS counter log rotation process `rotateIfNeeded_()` renamed the current log to an old log, then created a new one. 
- **Why it was an issue:** If a power failure occurred immediately after the rename but before the new log was written, the `load()` function would find no active log, default the counter to 0, and permanently reset the counter sequence. This exposed the system to replay attacks.
- **How we fixed it:** Modified `CounterStore::load()` to scan both the active log path and the old log path on boot, taking the maximum valid counter found across both files.

### 4. MSD Magic Bytes
- **What was the issue:** The system used `0xFFFF` (the Bluetooth SIG test ID) for its Manufacturer Specific Data (MSD) company ID.
- **Why it was an issue:** Other random devices in the wild using the `0xFFFF` test ID could trigger full MIC checks on the receiver, wasting power and CPU cycles.
- **How we fixed it:** Injected a 2-byte magic prefix (`0x494D` or `"IM"`) immediately after the company ID in the MSD payload. The receiver now filters for this magic sequence before proceeding to cryptographic verification.

### 5. Payload Plaintext Leakage
- **What was the issue:** The 5-byte payload (4-byte counter + 1-byte command) was authenticated via CCM-MAC but not encrypted.
- **Why it was an issue:** A passive sniffer could read the plaintext to see which command (lock/unlock) was sent and observe the counter to track usage frequency.
- **How we fixed it:** Replaced the pure CBC-MAC generation with full CCM authenticated encryption. The counter is passed as unencrypted Additional Authenticated Data (AAD) so the receiver can derive the nonce, while the 1-byte command is encrypted using the AES-CTR keystream.

### 6. Lack of Watchdog Timer (WDT)
- **What was the issue:** The Guillemot receiver had no Watchdog Timer configured.
- **Why it was an issue:** If the firmware hung (e.g., SoftDevice error or flash stall), the MCU would sleep forever.
- **How we fixed it:** Configured the nRF52840 hardware WDT with an 8-second timeout, continuously fed by the main `loop()`. If a hang occurs, the MCU reboots cleanly. Because Guillemot uses a hardware SR latch, the scooter does not lose power mid-ride; the hardware latch physically maintains the "unlocked" state while the firmware restarts.

---

## Part 2: Issues Not Pursued (Skipped/Rejected)

### 7. LittleFS Power Drain
- **What was the issue:** It was claimed that linearly scanning up to 512 LittleFS records on every button press wastes CPU and power.
- **Why it was an issue:** Reading flash sequentially takes a few milliseconds, slightly delaying the BLE broadcast.
- **Why we skipped it:** The full scan takes only ~2-5ms, which is completely negligible compared to the ~100-200ms boot time. Adding a `.noinit` RAM cache would unnecessarily complicate the code for a tiny, immaterial power saving.

### 8. Blocking the BLE Stack
- **What was the issue:** `handle_valid_command()` plays buzzer tones using a blocking `delay()`, stalling the BLE scanner for ~275ms.
- **Why it was an issue:** The scanner cannot receive packets while blocked.
- **Why we skipped it:** The fob sends ~30 duplicate packets over a 600ms window. Only the *first* valid packet needs to be received. Blocking after the first packet is accepted is completely fine. Dropping subsequent redundant duplicates doesn't hurt anything. Adding a FreeRTOS queue to decouple this was deemed an unnecessary complication.

### 9. Nonce Lacks Session Diversifier
- **What was the issue:** The nonce lacked a session ID, potentially allowing nonce reuse if the same key is reprovisioned.
- **Why it was an issue:** Nonce reuse in CCM completely breaks the encryption.
- **Why we skipped it:** The system already generates a *new* random key every time it is provisioned. Because the key is always new, the key-nonce pair is inherently globally unique. Adding a session diversifier would be completely redundant.

### 10. FreeRTOS LED Task Overkill
- **What was the issue:** Spawning a FreeRTOS task with 512 bytes of stack just to blink a blue LED during provisioning.
- **Why it was an issue:** Claimed to be a waste of memory and RTOS resources.
- **Why we skipped it:** This code only runs when USB-connected for provisioning, never during battery operation. It has zero impact on battery life or production use, and the memory footprint is trivial on the nRF52840's 256KB RAM.

### 11. Continuous 5% Duty Cycle
- **What was the issue:** The scanner's 25ms/500ms duty cycle draws ~250µA on average.
- **Why it was an issue:** Claimed to be a vampire drain on the scooter battery.
- **Why we skipped it:** At 250µA on a 15Ah scooter battery, it draws about 0.04% per day. The scooter would need to sit for ~7 years to drain from scanning alone. The duty cycle is already well-optimized and perfectly acceptable.

### 12. Manual CCM Instead of Hardware NRF_CCM
- **What was the issue:** The firmware manually implements CCM via ECB loops instead of using the hardware `NRF_CCM` peripheral.
- **Why it was an issue:** Software crypto is theoretically slower and uses more power than hardware crypto.
- **Why we skipped it:** The nRF52840 SoftDevice (S140) reserves the `NRF_CCM` peripheral for its own use; direct application access is blocked. The manual ECB-based CCM implementation is the standard and correct approach when using the SoftDevice.

### 13. `ccm_mic_8()` Return Value Unchecked
- **What was the issue:** The critique claimed the return value of the crypto function wasn't checked.
- **Why it was an issue:** Could potentially lead to accepting an uninitialized or failed MAC.
- **Why we skipped it:** The claim was factually incorrect. The codebase already properly checked the return value and rejected the payload on failure. No fix was needed.

### 14. No Delivery Confirmation
- **What was the issue:** The fob broadcasts blindly for 600ms and goes to sleep without an acknowledgment from the receiver.
- **Why it was an issue:** The user doesn't know for sure if the scooter received the command.
- **Why we skipped it:** This is an inherent architectural tradeoff. Adding an ACK would require a connection or a back-channel scanner on the fob, which would dramatically increase power consumption, complexity, and latency without proportionate benefit.

### 15. Hardware Design Hardening (e.g., Conformal Coating)
- **What was the issue:** The critique pointed out missing production hardening features (reverse polarity protection, TVS overshoot, ESD protection, conformal coating).
- **Why it was an issue:** These are best practices for mass production reliability.
- **Why we skipped it:** While well noted for future hardware revisions, these are not showstoppers for the current prototype design. Implementing these (e.g., conformal coating, schematic restructuring) was explicitly decided against for this iteration.

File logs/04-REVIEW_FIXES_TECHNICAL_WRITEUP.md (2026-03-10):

# Technical Fixes for Codebase Review Findings

*Date: 2026-03-09 06:21*

*Proposed solutions for all valid findings from CODEBASE_REVIEW_FINDINGS.md.*

---

## 1. Unprovisioned Receiver (Guillemot) — **HIGH**

**Problem:** Unprovisioned receiver accepts commands; attacker with zero key can craft valid MIC.

**Fix:** Add early return in `scan_callback` before `verify_payload`:

```cpp
void scan_callback(ble_gap_evt_adv_report_t* report) {
  immo::Payload pl{};
  if (!parse_payload_from_report(report, pl)) return;
  if (key_is_all_zeros()) return;  // Reject when unprovisioned
  if (!verify_payload(pl)) return;
  handle_valid_command(pl);
}
```

**File:** `Guillemot/firmware/guillemot/src/main.cpp`

---

## 2. Uguisu Counter Persistence Order — **HIGH**

**Problem:** `g_store.update(counter)` runs after `delay(UGUISU_ADVERTISE_MS)`; power loss during that window causes counter reuse and replay on next boot.

**Fix:** Persist counter before advertising (or at least before the long delay):

```cpp
// Persist first; if storage fails, abort before advertising
g_store.update(counter);
start_advertising_once(MSD_COMPANY_ID, payload13);
delay(UGUISU_ADVERTISE_MS);
system_off();
```

If you need to avoid advancing counter before advertising succeeds, alternative: persist at the *start* of the advertise phase (before `delay`), so the ~2s window is eliminated—worst case is power loss mid-advertise, but counter is already saved.

**File:** `Uguisu/firmware/uguisu/src/main.cpp`

---

## 3. Guillemot Lock/Counter Order — **MEDIUM**

**Problem:** Latch/buzzer actions run before `g_store.update()`. If update fails, physical state changed but counter not persisted; next unlock may be rejected as replay.

**Fix:** Update counter before or as close as possible to the physical action. Option A—update first, then act:

```cpp
case immo::Command::Unlock:
  g_store.update(pl.counter);
  latch_set_pulse();
  buzzer_tone_ms(BUZZER_UNLOCK_MS);
  break;
case immo::Command::Lock:
  g_store.update(pl.counter);
  buzzer_tone_ms(BUZZER_LOCK_MS);
  latch_reset_pulse();
  break;
```

**Caveat:** If `update()` fails, you could add error handling (e.g. retry, abort, or document that failure leaves system in undefined state). Document failure behavior in comments or design doc.

**File:** `Guillemot/firmware/guillemot/src/main.cpp`

---

## 4. Stricter Checksum Validation (immo_provisioning) — **MEDIUM**

**Problem:** `strlen(checksum_hex) < 4` allows trailing garbage; only first 4 hex chars are validated.

**Fix:** Require exactly 4 hex chars. After parsing `checksum_hex`:

```cpp
// Replace: strlen(checksum_hex) < 4
// With: require exactly 4 hex chars
if ((size_t)(col1 - key_hex) != 32 || (size_t)(col2 - counter_hex) != 8) {
  Serial.println("ERR:MALFORMED");
  return false;
}
// Validate checksum is exactly 4 hex chars
const char* checksum_hex = col2 + 1;
if (strlen(checksum_hex) != 4) {
  Serial.println("ERR:MALFORMED");
  return false;
}
for (int i = 0; i < 4; i++) {
  char c = checksum_hex[i];
  if (!((c >= '0' && c <= '9') || (c >= 'a' && c <= 'f') || (c >= 'A' && c <= 'F'))) {
    Serial.println("ERR:MALFORMED");
    return false;
  }
}
```

Or use a helper that returns false if any char after the 4th is non-whitespace/non-null.

**File:** `ImmoCommon/src/immo_provisioning.cpp` (and mirrored copies in Guillemot/Uguisu libs)

---

## 5. Document BLE Scan/Advert Timing — **MEDIUM**

**Problem:** Guillemot 1% duty cycle scan can miss Uguisu adverts; worst-case latency can reach several seconds.

**Fix:** Documentation only. Add to design/architecture docs:

- Guillemot: `SCAN_INTERVAL_MS=2000`, `SCAN_WINDOW_MS=20` (1% duty cycle).
- Uguisu: adverts every ~100 ms for ~2 s.
- Worst-case: if scan window falls between adverts, user may need to hold button and retry; worst-case latency ~2–4 seconds.
- Recommend documenting this in user-facing docs (e.g. “hold fob button for 2–3 seconds near MCU”).

**Files:** `Guillemot/README.md`, `Uguisu/README.md`, or `logs/CODEBASE_TECHNICAL_WRITEUP.md`

---

## 6. ensure_provisioned Timeout Option — **LOW**

**Problem:** When VBUS present and not provisioned, loop runs indefinitely; can block boot when USB plugged but no host connected.

**Fix:** Add optional max attempts or cumulative timeout. For example:

```cpp
void ensure_provisioned(
    uint32_t timeout_ms,
    bool (*on_success)(...),
    void (*load_provisioning)(),
    bool (*is_provisioned)(),
    uint32_t max_attempts = 0  // 0 = infinite (current behavior)
) {
  if (prov_is_vbus_present()) {
    prov_run_serial_loop(timeout_ms, on_success);
    if (load_provisioning) load_provisioning();
  }
  uint32_t attempts = 0;
  while (is_provisioned && !is_provisioned() && prov_is_vbus_present()) {
    if (max_attempts > 0 && ++attempts >= max_attempts) break;
    prov_run_serial_loop(timeout_ms, on_success);
    if (load_provisioning) load_provisioning();
  }
}
```

Callers who need non-blocking behavior can pass e.g. `max_attempts=3`; default `0` preserves current behavior.

**File:** `ImmoCommon/src/immo_provisioning.cpp`

---

## 7. load() Partial-Record Handling — **LOW**

**Problem:** Truncated write could leave half-record; `read` returning partial bytes exits loop but no explicit detection or recovery.

**Fix:** Add basic detection and optional recovery:

```cpp
void CounterStore::load() {
  last_counter_ = 0;
  Adafruit_LittleFS_Namespace::File f(InternalFS.open(log_path_, ...));
  if (!f) return;

  CounterRecord rec{};
  while (true) {
    const size_t n = f.read(reinterpret_cast<void*>(&rec), sizeof(rec));
    if (n == 0) break;
    if (n != sizeof(rec)) {
      // Partial record; stop to avoid using corrupt data
      break;
    }
    if (record_crc(rec.counter) != rec.crc32) continue;
    last_counter_ = rec.counter;
  }
}
```

Optional: if partial read detected, log or set a “dirty” flag for diagnostics. Avoid using the partial record.

**File:** `ImmoCommon/src/immo_storage.cpp`

---

## 8. rotateIfNeeded_ When Log Doesn't Exist — **LOW**

**Problem:** Behavior of `f.size()` when file doesn't exist should be verified.

**Fix:** Adafruit LittleFS `open` with `FILE_O_READ` on non-existent file typically returns invalid/falsy handle; `if (!f) return` already guards. Add an explicit check for clarity:

```cpp
void CounterStore::rotateIfNeeded_() {
  Adafruit_LittleFS_Namespace::File f(InternalFS.open(log_path_, FILE_O_READ));
  if (!f) return;  // File doesn't exist or open failed
  const size_t sz = f.size();
  f.close();
  // ...
}
```

Document in comment: “When log file doesn't exist, open fails and we return early; f.size() is never called.”

**File:** `ImmoCommon/src/immo_storage.cpp`

---

## 9. serial.js: Document No Concurrent Use — **LOW**

**Problem:** Multiple concurrent `readLineWithTimeout` calls resolve in FIFO order; lines can be routed to wrong consumer.

**Fix:** Documentation only. Add to `serial.js` or `Whimbrel` README:

```js
/**
 * readLineWithTimeout: Reads one line with optional timeout.
 * WARNING: Concurrent calls are not supported. Lines are delivered FIFO to
 * the first waiter; use sequentially (e.g. send request → readLine → send next).
 */
```

**File:** `Whimbrel/js/serial.js`

---

## 10. dfu.js: Document Response Matching Fragility — **LOW**

**Problem:** Responses matched by opcode only; some Nordic DFU ops emit multiple responses; out-of-order or duplicate responses could misroute.

**Fix:** Documentation only. Add comment or docblock:

```js
/**
 * receiveResponse: Matches by opcode only. Some Nordic DFU operations
 * (e.g. PRN) may emit multiple responses. Acceptable for standard
 * single-request flows; may misroute in edge cases with concurrent or
 * duplicate responses.
 */
```

**File:** `Whimbrel/js/dfu.js`

---

## Summary Table

| Priority | Issue | Fix Type | Location |
|---|---|---|---|
| High | Unprovisioned receiver | Code | Guillemot main.cpp |
| High | Uguisu counter persistence order | Code | Uguisu main.cpp |
| Medium | Guillemot lock/counter order | Code | Guillemot main.cpp |
| Medium | Stricter checksum validation | Code | immo_provisioning.cpp |
| Medium | BLE scan/advert timing | Docs | Architecture/README |
| Low | ensure_provisioned timeout | Code | immo_provisioning.cpp |
| Low | load() partial-record handling | Code | immo_storage.cpp |
| Low | rotateIfNeeded_ file existence | Code + comment | immo_storage.cpp |
| Low | serial.js concurrency | Docs | serial.js |
| Low | dfu.js response matching | Docs | dfu.js |

---

## Implementation Notes

- **ImmoCommon copies:** Guillemot and Uguisu each have `lib/ImmoCommon`; changes to provisioning/storage should be made in the root `ImmoCommon/` and propagated (or use a single source via submodule/symlink).
- **Testing:** After fixes, verify: (1) unprovisioned Guillemot rejects adverts, (2) Uguisu survives power loss during advertise, (3) provisioning flow still works, (4) lock/unlock with storage failure scenarios if testable.

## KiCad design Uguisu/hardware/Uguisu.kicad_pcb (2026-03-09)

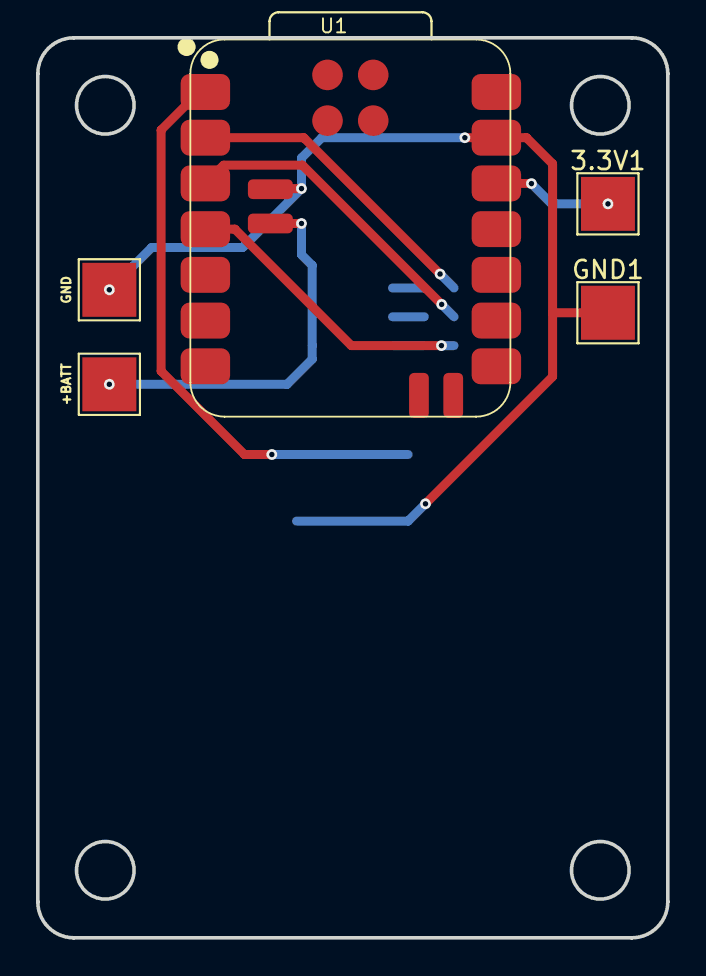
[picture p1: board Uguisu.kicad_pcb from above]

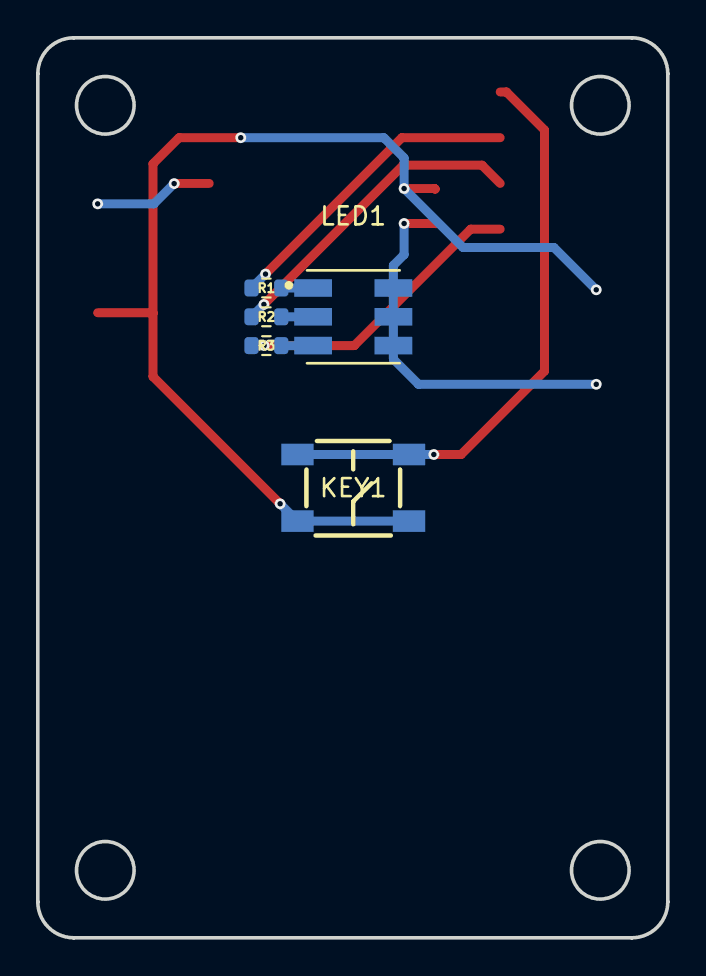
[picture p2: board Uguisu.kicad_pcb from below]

Board: 2 copper layers, 35.0 x 50.0 mm, 10 parts (5 on the bottom side), 10 nets.

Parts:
3.3V1: 3.3V; TestPoint_Pad_3.0x3.0mm
+BATT: +BATT; TestPoint_Pad_3.0x3.0mm
GND, GND1: GND; TestPoint_Pad_3.0x3.0mm
KEY1: SKQGABE010; KEY-SMD_4P-L5.2-W5.2-P3.70-LS6.4
LED1: XL-5050RGBC; LED-ARRAY-SMD_6P-L5.0-W5.0-TL-RD_3
R1, R3: 120; R_0603_1608Metric
R2: 330; R_0603_1608Metric
U1: XIAO-nRF52840-SMD

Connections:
+BATT: +BATT.1, LED1.4 (G+), LED1.5 (R+), LED1.6 (B+), U1.32 (BAT)
/3.3V: 3.3V1.1, U1.12 (3V3)
/MCU_D0: KEY1.1, KEY1.2, U1.1 (P0.02_A0_D0)
/MCU_D1: R1.2, U1.2 (P0.03_A1_D1)
/MCU_D2: R2.2, U1.3 (P0.28_A2_D2)
/MCU_D3: R3.1, U1.4 (P0.29_A3_D3)
GND: GND.1, GND1.1, KEY1.3, KEY1.4, U1.13 (GND), U1.33 (GND)
unnamed: LED1.1 (B-), R1.1
unnamed: LED1.3 (G-), R3.2
unnamed: LED1.2 (R-), R2.1

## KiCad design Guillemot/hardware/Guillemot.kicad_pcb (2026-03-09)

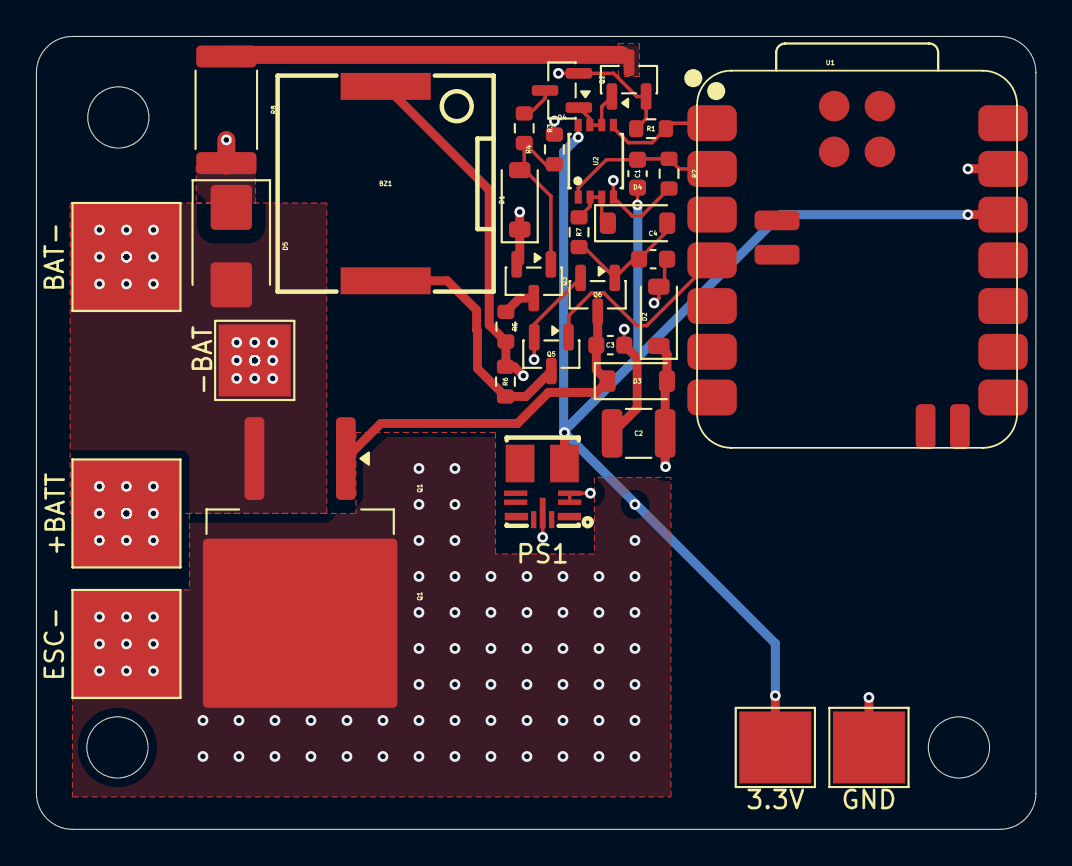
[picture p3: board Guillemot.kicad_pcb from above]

Board: 4 copper layers, 55.5 x 44.0 mm, 33 parts (0 on the bottom side), 17 nets.

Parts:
3.3V: 3.3V; TestPoint_Pad_4.0x4.0mm
+BATT: ESC+; TestPoint_Pad_6.0x6.0mm
-BAT: WIRE; TestPoint_Pad_4.0x4.0mm
BAT-: BAT-; TestPoint_Pad_6.0x6.0mm
BZ1: FUET-1230; BUZ-SMD_L12.0-W12.0_FUET-1230
C1: 10nF; C_0603_1608Metric
C2: 100µF; C_1210_3225Metric
C3, C4: 1uF; C_0603_1608Metric
D1: BZT52C12-7-F; D_SOD-123
D2: BZT52C10-7-F; D_SOD-123
D3, D4: 1N4148W; D_SOD-123
D5: SMBJ45A; D_SMB
ESC-: ESC-; TestPoint_Pad_6.0x6.0mm
GND: GND; TestPoint_Pad_4.0x4.0mm
PS1: TPSM365R6V3RDNR; QFN-11_L4.5-W3.5-P0.50-TL_TPSM365R6FRDNR
Q1: IPB042N10N3G; TO-263-2
Q2: AO3422; SOT-23
Q3: SI2309CDS; SOT-23
Q4: 2N7002; SOT-23
Q5, Q6: MMBT3904; SOT-23
R1, R2, R3, R7: 100k; R_0603_1608Metric
R4: 1M; R_0603_1608Metric
R5: 10k; R_0603_1608Metric
R6: 4.7k; R_0603_1608Metric
R8: 47 2W; R_2512_6332Metric
U1: XIAO-nRF52840-SMD
U2: SN74LVC2G02DCTR; MSOP-8_L2.9-W2.8-P0.65-LS4.0-BR

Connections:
+BATT: +BATT.1, D1.1 (K), PS1.2 (EN), PS1.3 (VIN), Q3.2 (S), R4.2
/3.3V: 3.3V.1, C1.2, PS1.4 (VOUT), U1.12 (3V3), U2.8 (VCC)
/10V_RAIL: BZ1.1 (+), C2.1, D2.1 (K), D3.2 (A), R5.2, R6.1
/10V_RAW: Q3.3 (D), R5.1
/BUZZER_SINK: BZ1.2, Q5.3 (C), R6.2
/ESC-: D5.1 (A1), ESC-.1, Q1.2 (D), R8.2
/ISO_GATE: C3.1, D3.1 (K), Q1.1 (G), Q6.3 (C)
/MCU_D0: R1.1, U1.1 (P0.02_A0_D0), U2.5 (2A)
/MCU_D1: C1.1, R2.1, U1.2 (P0.03_A1_D1), U2.1 (1A)
/MCU_D3: Q5.1 (B), U1.4 (P0.29_A3_D3)
/NPN_BASE: C4.1, D4.2 (A), Q6.1 (B), R7.2
/PFET_CTRL: Q4.3 (D), R3.1
/PFET_GATE: D1.2 (A), Q3.1 (G), R3.2, R4.1
/PRECHARGE_OUT: Q2.3 (D), R8.1
/QBAR_LOCK: D4.1 (K), R7.1, U2.2 (1B), U2.3 (2Y)
/Q_UNLOCK: Q2.1 (G), Q4.1 (G), U2.6 (2B), U2.7 (1Y)
GND: -BAT.1, BAT-.1, C2.2, C3.2, C4.2, D2.2 (A), D5.2 (A2), GND.1, PS1.10 (GND), Q1.3 (S), Q2.2 (S), Q4.2 (S), Q5.2 (E), Q6.2 (E), R1.2, R2.2, U1.13 (GND), U2.4 (GND)

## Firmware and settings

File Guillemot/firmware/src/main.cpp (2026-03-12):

#include <Arduino.h>

#include <bluefruit.h>
#include <nrf_soc.h>
#include <nrf_wdt.h>

#include <Adafruit_LittleFS.h>
#include <InternalFileSystem.h>

#include "guillemot_config.h"
#include <ImmoCommon.h>
#include <ArduinoJson.h>

using namespace Adafruit_LittleFS_Namespace;

namespace {

static constexpr const char* COUNTER_LOG_PATH = "/ctr.log";
static constexpr const char* OLD_COUNTER_LOG_PATH = "/ctr.old";

// PIN rate limiting
static constexpr uint32_t PIN_LOCKOUT_MS = 60 * 60 * 1000; // 1 hour
uint8_t g_pin_failures = 0;
uint32_t g_pin_lockout_start = 0;

// Hardware state
bool g_locked = true;

// Window state
uint32_t g_window_end_ms = 0;
bool g_window_active = false;
uint32_t g_window_remaining_ms = 0; // For pausing during GATT connection
static constexpr uint32_t WINDOW_DURATION_MS = 30000;

// Forward declaration
void send_json_response(const JsonDocument& doc);
void process_management_command(String cmd, bool is_serial, bool is_authenticated = false);

// Session identity tracking
int8_t g_session_slot = -1; // -1 if not identified, 0-3 for key slot

// Runtime keys: loaded from flash (Whimbrel-provisioned)
immo::KeySlot g_slots[immo::MAX_KEY_SLOTS];
char g_smp_pin[7] = "000000";

immo::CounterStore g_store(COUNTER_LOG_PATH, OLD_COUNTER_LOG_PATH, immo::DEFAULT_COUNTER_LOG_MAX_BYTES);

// BLE GATT Services & Characteristics
BLEService proximityService("942C7A1E-362E-4676-A22F-39130FAF2272");
BLECharacteristic unlockLockChr("2522DA08-9E21-47DB-A834-22B7267E178B");
BLECharacteristic mgmtCmdChr("438C5641-3825-40BE-80A8-97BC261E0EE9");
BLECharacteristic mgmtRspChr("DA43E428-803C-401B-9915-4C1529F453B1");

// iBeacon UUID
uint8_t iBeaconUuid[16] = {
  0x66, 0x96, 0x2B, 0x67, 0x9C, 0x59, 0x4D, 0x83,
  0x91, 0x01, 0xAC, 0x0C, 0x9C, 0xCA, 0x2B, 0x12
};
BLEBeacon iBeacon(iBeaconUuid, 0x0000, 0x0000, -54);

// Proximity Beacon UUIDs for Scan Response
uint8_t uuidLocked[16] = {
  0xC5, 0x38, 0x0E, 0xF2, 0xC3, 0xFC, 0x4F, 0x2A,
  0xB3, 0xCC, 0xD5, 0x1A, 0x08, 0xEF, 0x5F, 0xA9
};
uint8_t uuidUnlocked[16] = {
  0xA1, 0xAA, 0x4F, 0x79, 0xB4, 0x90, 0x44, 0xD2,
  0xA7, 0xE1, 0x8A, 0x03, 0x42, 0x22, 0x43, 0xA1
};
uint8_t uuidWindow[16] = {
  0xB9, 0x9F, 0x8D, 0x62, 0xA1, 0xC3, 0x4E, 0x8B,
  0x9D, 0x2F, 0x5C, 0x3A, 0x1B, 0x4E, 0x6D, 0x7A
};
BLEUuid bleUuidLocked(uuidLocked);
BLEUuid bleUuidUnlocked(uuidUnlocked);
BLEUuid bleUuidWindow(uuidWindow);

void update_advertising();

bool on_provision_success(const uint8_t key[16], uint32_t counter) {
  // Save Slot 1 via new method
  memcpy(g_slots[1].aes_key, key, 16);
  g_slots[1].counter = counter;
  strncpy(g_slots[1].name, "Owner's Phone", sizeof(g_slots[1].name) - 1);
  
  File f = InternalFS.open("/slot1.dat", FILE_O_WRITE);
  if (f) {
      f.write(g_slots[1].aes_key, 16);
      f.write((uint8_t*)&g_slots[1].counter, 4);
      f.write(g_slots[1].name, sizeof(g_slots[1].name));
      f.close();
  }

  return immo::prov_write_and_verify(immo::DEFAULT_PROV_PATH, key, counter, g_store, g_slots[1].aes_key);
}

static bool key_is_all_zeros(const uint8_t key[16]) {
  for (int i = 0; i < 16; i++) {
    if (key[i] != 0) return false;
  }
  return true;
}

static bool slot_1_is_empty() {
  return key_is_all_zeros(g_slots[1].aes_key);
}

static void load_psk_from_storage() {
  memset(g_slots, 0, sizeof(g_slots));
  
  // Load each slot from LittleFS
  for (int i=0; i<immo::MAX_KEY_SLOTS; i++) {
      String filePath = String("/slot") + i + ".dat";
      File f = InternalFS.open(filePath.c_str(), FILE_O_READ);
      if (f) {
          f.read(g_slots[i].aes_key, 16);
          f.read((uint8_t*)&g_slots[i].counter, 4);
          f.read((uint8_t*)g_slots[i].name, sizeof(g_slots[i].name));
          f.close();
      }
  }

  // Fallback to legacy prov logic for Slot 1 if /slot1.dat didn't exist
  if (key_is_all_zeros(g_slots[1].aes_key)) {
      immo::prov_load_key_or_zero(immo::DEFAULT_PROV_PATH, g_slots[1].aes_key); 
  }
  
  // NOTE: Assuming PIN is also stored or using a default. For simplicity, reading PIN from flash if possible,
  // but if SETPIN serial command is only way to set it, we might need to store it.
  File f = InternalFS.open("/pin.txt", FILE_O_READ);
  if (f) {
    f.read(g_smp_pin, 6);
    g_smp_pin[6] = 0;
    f.close();
  }
}

void buzzer_tone_ms(uint16_t hz, uint16_t duration_ms) {
  tone(PIN_BUZZER, hz, duration_ms);
  delay(duration_ms);
  noTone(PIN_BUZZER);
}

bool parse_payload_from_report(ble_gap_evt_adv_report_t* report, uint8_t ct[immo::MSG_LEN], uint8_t mic[immo::MIC_LEN]) {
  uint8_t msd[4 + immo::PAYLOAD_LEN];
  const uint8_t len = Bluefruit.Scanner.parseReportByType(report, BLE_GAP_AD_TYPE_MANUFACTURER_SPECIFIC_DATA, msd, sizeof(msd));
  if (len != sizeof(msd)) return false;

  const uint16_t company_id = static_cast<uint16_t>(msd[0] | (static_cast<uint16_t>(msd[1]) << 8));
  if (company_id != MSD_COMPANY_ID) return false;

  const uint16_t magic = static_cast<uint16_t>(msd[2] | (static_cast<uint16_t>(msd[3]) << 8));
  if (magic != immo::IMMOGEN_MAGIC) return false;

  const uint8_t* p = msd + 4;
  memcpy(ct, p, immo::MSG_LEN);
  memcpy(mic, p + immo::MSG_LEN, immo::MIC_LEN);
  return true;
}

void handle_valid_command(const immo::Payload& pl, uint8_t slot_id) {
  const uint32_t last = g_store.lastCounter();
  if (pl.counter <= last) return;

  g_store.update(pl.counter);

  // Valid AES-CCM Lock/Unlock instantly resets PIN failure counter
  if (pl.command == immo::Command::Lock || pl.command == immo::Command::Unlock) {
      g_pin_failures = 0;
      g_pin_lockout_start = 0;
  }

  bool state_changed = false;

  switch (pl.command) {
    case immo::Command::Unlock:
      if (g_locked) {
          latch_set_pulse();
          buzzer_tone_ms(BUZZER_LOW_HZ,  BUZZER_LOW_MS);
          buzzer_tone_ms(BUZZER_HIGH_HZ, BUZZER_HIGH_MS);
          g_locked = false;
          state_changed = true;
      }
      break;
    case immo::Command::Lock:
      if (!g_locked) {
          buzzer_tone_ms(BUZZER_HIGH_HZ, BUZZER_HIGH_MS);
          buzzer_tone_ms(BUZZER_LOW_HZ,  BUZZER_LOW_MS);
          latch_reset_pulse();
          g_locked = true;
          state_changed = true;
      }
      break;
    case immo::Command::Identify:
      g_session_slot = (pl.prefix >> 4) & 0x03;
      break;
    case immo::Command::Window:
      if (slot_id == 0) { // Only Uguisu can open the window
          g_window_active = true;
          g_window_end_ms = millis() + WINDOW_DURATION_MS;
          g_window_remaining_ms = WINDOW_DURATION_MS;
          // Three fast beeps at 4 kHz
          for (int i = 0; i < 3; i++) {
              buzzer_tone_ms(4000, 100);
              delay(50);
          }
          state_changed = true;
      }
      break;
    default:
      // Ignore unknown commands
      break;
  }

  if (state_changed) {
      update_advertising();
  }
}

void scan_callback(ble_gap_evt_adv_report_t* report) {
  uint8_t ct[immo::MSG_LEN];
  uint8_t mic[immo::MIC_LEN];
  if (!parse_payload_from_report(report, ct, mic)) return;
  
  immo::Payload pl{};
  uint8_t slot_id;
  if (!immo::verify_payload(ct, mic, g_slots, pl, slot_id)) return;
  handle_valid_command(pl, slot_id);
}

void unlock_lock_write_callback(uint16_t conn_hdl, BLECharacteristic* chr, uint8_t* data, uint16_t len) {
    if (len != immo::PAYLOAD_LEN) return;
    uint8_t ct[immo::MSG_LEN];
    uint8_t mic[immo::MIC_LEN];
    memcpy(ct, data, immo::MSG_LEN);
    memcpy(mic, data + immo::MSG_LEN, immo::MIC_LEN);
    
    immo::Payload pl{};
    uint8_t slot_id;
    if (!immo::verify_payload(ct, mic, g_slots, pl, slot_id)) return;
    handle_valid_command(pl, slot_id);
}

void send_json_response(const JsonDocument& doc) {
    char buf[247];
    size_t len = serializeJson(doc, buf, sizeof(buf));
    if (Bluefruit.connected() && mgmtRspChr.notifyEnabled()) {
        mgmtRspChr.notify(buf, len);
    }
    Serial.println(buf);
}

void process_management_command(String cmd, bool is_serial, bool is_authenticated) {
    StaticJsonDocument<512> rsp;
    rsp["status"] = "error";

    // Split command by ':'
    int max_parts = 6;
    String parts[max_parts];
    int part_count = 0;
    int start_idx = 0;
    while (start_idx < (int)cmd.length() && part_count < max_parts) {
        int colon_idx = cmd.indexOf(':', start_idx);
        if (colon_idx == -1) {
            parts[part_count++] = cmd.substring(start_idx);
            break;
        } else {
            parts[part_count++] = cmd.substring(start_idx, colon_idx);
            start_idx = colon_idx + 1;
        }
    }

    String action = parts[0];

    if (action == "SETPIN") {
        if (!is_serial && !(g_window_active && slot_1_is_empty())) {
            rsp["reason"] = "serial_or_window_only";
        } else if (part_count >= 2) {
            String pinStr = parts[1];
            pinStr.trim();
            if (pinStr.length() == 6) {
                strncpy(g_smp_pin, pinStr.c_str(), 6);
                g_smp_pin[6] = 0;
                Bluefruit.Security.setPIN(g_smp_pin);
                File f = InternalFS.open("/pin.txt", FILE_O_WRITE);
                if (f) {
                    f.write(g_smp_pin, 6);
                    f.close();
                }
                rsp["status"] = "ok";
            } else {
                rsp["reason"] = "invalid_pin";
            }
        } else {
             rsp["reason"] = "missing_args";
        }
    } else if (action == "RESETLOCK") {
        if (!is_serial && !(g_window_active && slot_1_is_empty())) {
            rsp["reason"] = "serial_or_window_only";
        } else {
            InternalFS.format();
            rsp["status"] = "ok";
            send_json_response(rsp);
            delay(100);
            NVIC_SystemReset();
        }
    } else if (action == "PROV") {
        if (!is_serial && g_session_slot != 1 && !(g_window_active && slot_1_is_empty() && parts[1].toInt() == 1)) {
            rsp["reason"] = "forbidden";
        } else if (part_count >= 4) {
            int slot = parts[1].toInt();
            if (slot >= 0 && slot < immo::MAX_KEY_SLOTS) {
                // Parse hex key
                String keyStr = parts[2];
                if (keyStr.length() == 32) {
                     for (int i=0; i<16; i++) {
                         g_slots[slot].aes_key[i] = strtol(keyStr.substring(i*2, i*2+2).c_str(), NULL, 16);
                     }
                     g_slots[slot].counter = parts[3].toInt();
                     if (part_count >= 5) {
                         strncpy(g_slots[slot].name, parts[4].c_str(), sizeof(g_slots[slot].name) - 1);
                     } else {
                         g_slots[slot].name[0] = '\0';
                     }
                     
                     // In reality, save to LittleFS here (e.g. "/slotX.dat")
                     String filePath = String("/slot") + slot + ".dat";
                     File f = InternalFS.open(filePath.c_str(), FILE_O_WRITE);
                     if (f) {
                         f.write(g_slots[slot].aes_key, 16);
                         f.write((uint8_t*)&g_slots[slot].counter, 4);
                         f.write(g_slots[slot].name, sizeof(g_slots[slot].name));
                         f.close();
                     }

                     rsp["status"] = "ok";
                     rsp["slot"] = slot;
                     rsp["name"] = g_slots[slot].name;
                     rsp["counter"] = g_slots[slot].counter;
                } else {
                     rsp["reason"] = "invalid_key_length";
                }
            } else {
                rsp["reason"] = "invalid_slot";
            }
        } else {
             rsp["reason"] = "missing_args";
        }
    } else if (action == "RENAME") {
        if (!is_serial && g_session_slot != 1) {
            rsp["reason"] = "forbidden";
        } else if (part_count >= 3) {
            int slot = parts[1].toInt();
            if (slot >= 0 && slot < immo::MAX_KEY_SLOTS) {
                strncpy(g_slots[slot].name, parts[2].c_str(), sizeof(g_slots[slot].name) - 1);
                // Save to LittleFS
                String filePath = String("/slot") + slot + ".dat";
                File f = InternalFS.open(filePath.c_str(), FILE_O_WRITE);
                if (f) {
                    f.write(g_slots[slot].aes_key, 16);
                    f.write((uint8_t*)&g_slots[slot].counter, 4);
                    f.write(g_slots[slot].name, sizeof(g_slots[slot].name));
                    f.close();
                }
                rsp["status"] = "ok";
                rsp["slot"] = slot;
                rsp["name"] = g_slots[slot].name;
            } else {
                rsp["reason"] = "invalid_slot";
            }
        } else {
            rsp["reason"] = "missing_args";
        }
    } else if (action == "SLOTS?") {
        rsp["status"] = "ok";
        JsonArray slots = rsp.createNestedArray("slots");
        for (int i=0; i<immo::MAX_KEY_SLOTS; i++) {
             JsonObject slotObj = slots.createNestedObject();
             slotObj["id"] = i;
             slotObj["used"] = !key_is_all_zeros(g_slots[i].aes_key);
             slotObj["counter"] = g_slots[i].counter;
             slotObj["name"] = g_slots[i].name;
        }
    } else if (action == "REVOKE") {
        if (!is_serial && g_session_slot != 1) {
            rsp["reason"] = "forbidden";
        } else if (part_count >= 2) {
            int slot = parts[1].toInt();
            if (slot >= 0 && slot < immo::MAX_KEY_SLOTS) {
                memset(g_slots[slot].aes_key, 0, 16);
                g_slots[slot].counter = 0;
                g_slots[slot].name[0] = '\0';
                String filePath = String("/slot") + slot + ".dat";
                InternalFS.remove(filePath.c_str());
                rsp["status"] = "ok";
                rsp["slot"] = slot;
            } else {
                rsp["reason"] = "invalid_slot";
            }
        } else {
             rsp["reason"] = "missing_args";
        }
    } else if (action == "RECOVER") {
        if (!is_serial && (!g_window_active || g_locked)) {
             rsp["reason"] = "forbidden_no_window_or_locked";
        } else if (part_count >= 4) {
            int slot = parts[1].toInt();
            if (slot == 1 && !is_serial && !is_authenticated) {
                 // RECOVER:1 requires SMP authenticated link if not serial
                 rsp["reason"] = "forbidden_needs_auth";
            } else if (slot >= 0 && slot < immo::MAX_KEY_SLOTS) {
                String keyStr = parts[2];
                if (keyStr.length() == 32) {
                     for (int i=0; i<16; i++) {
                         g_slots[slot].aes_key[i] = strtol(keyStr.substring(i*2, i*2+2).c_str(), NULL, 16);
                     }
                     g_slots[slot].counter = parts[3].toInt();
                     if (part_count >= 5) {
                         strncpy(g_slots[slot].name, parts[4].c_str(), sizeof(g_slots[slot].name) - 1);
                     } else {
                         g_slots[slot].name[0] = '\0';
                     }
                     
                     String filePath = String("/slot") + slot + ".dat";
                     File f = InternalFS.open(filePath.c_str(), FILE_O_WRITE);
                     if (f) {
                         f.write(g_slots[slot].aes_key, 16);
                         f.write((uint8_t*)&g_slots[slot].counter, 4);
                         f.write(g_slots[slot].name, sizeof(g_slots[slot].name));
                         f.close();
                     }

                     rsp["status"] = "ok";
                     rsp["slot"] = slot;
                     rsp["name"] = g_slots[slot].name;
                     rsp["counter"] = g_slots[slot].counter;
                } else {
                     rsp["reason"] = "invalid_key_length";
                }
            } else {
                rsp["reason"] = "invalid_slot";
            }
        } else {
             rsp["reason"] = "missing_args";
        }
    } else if (action == "IDENTIFY") {
         rsp["reason"] = "use_binary_payload";
    } else {
        rsp["reason"] = "unknown_command";
    }

    send_json_response(rsp);
}

void mgmt_cmd_write_callback(uint16_t conn_hdl, BLECharacteristic* chr, uint8_t* data, uint16_t len) {
    // If it's 14 bytes exactly, it might be an IDENTIFY binary payload
    if (len == immo::PAYLOAD_LEN) {
        uint8_t ct[immo::MSG_LEN];
        uint8_t mic[immo::MIC_LEN];
        memcpy(ct, data, immo::MSG_LEN);
        memcpy(mic, data + immo::MSG_LEN, immo::MIC_LEN);
        
        immo::Payload pl{};
        uint8_t slot_id;
        if (immo::verify_payload(ct, mic, g_slots, pl, slot_id)) {
             if (pl.command == immo::Command::Identify) {
                  const uint32_t last = g_store.lastCounter();
                  if (pl.counter > last) {
                      g_store.update(pl.counter);
                      g_session_slot = slot_id;
                      StaticJsonDocument<256> rsp;
                      rsp["status"] = "ok";
                      rsp["action"] = "IDENTIFY";
                      send_json_response(rsp);
                  }
             }
        }
        return; // Handled as binary
    }

    char buf[248];
    uint16_t copy_len = len < 247 ? len : 247;
    memcpy(buf, data, copy_len);
    buf[copy_len] = '\0';
    String cmd(buf);

    // Some commands don't need IDENTIFY
    if (cmd == "SLOTS?" || cmd.startsWith("RECOVER:")) {
        // Allow
    } else if (g_session_slot == -1) {
        // Must be IDENTIFY'd first for other commands
        StaticJsonDocument<256> rsp;
        rsp["status"] = "error";
        rsp["reason"] = "unidentified";
        send_json_response(rsp);
        return; 
    }
    
    // Check if the connection is authenticated (has SMP bonding/PIN)
    bool is_auth = false;
    ble_gap_conn_sec_t sec;
    if (sd_ble_gap_conn_sec_get(conn_hdl, &sec) == NRF_SUCCESS) {
        is_auth = (sec.sec_mode.sm >= 1 && sec.sec_mode.lv >= 2);
    }
    
    process_management_command(cmd, false, is_auth);
}

void prph_connect_callback(uint16_t conn_handle) {
    g_session_slot = -1; // Reset identity on connection
    if (g_window_active) {
        if (millis() < g_window_end_ms) {
            g_window_remaining_ms = g_window_end_ms - millis();
        } else {
            g_window_remaining_ms = 0;
            g_window_active = false;
        }
    }
}

void prph_disconnect_callback(uint16_t conn_handle, uint8_t reason) {
    g_session_slot = -1;
    if (g_window_active) {
        g_window_end_ms = millis() + g_window_remaining_ms;
    }
}

void update_advertising() {
    Bluefruit.Advertising.stop();
    Bluefruit.Advertising.clearData();
    Bluefruit.ScanResponse.clearData();
    
    Bluefruit.Advertising.setBeacon(iBeacon);

    // Scan Response packet for Proximity UUID
    if (g_window_active) {
        Bluefruit.ScanResponse.addUuid(bleUuidWindow);
        Bluefruit.Advertising.setInterval(160, 160); // 100 ms (160 * 0.625)
    } else if (g_locked) {
        Bluefruit.ScanResponse.addUuid(bleUuidLocked);
        Bluefruit.Advertising.setInterval(480, 480); // 300 ms (480 * 0.625)
    } else {
        Bluefruit.ScanResponse.addUuid(bleUuidUnlocked);
        Bluefruit.Advertising.setInterval(320, 320); // 200 ms (320 * 0.625)
    }
    
    Bluefruit.Advertising.restartOnDisconnect(true);
    Bluefruit.Advertising.start(0);
}

void pairing_complete_callback(uint16_t conn_handle, uint8_t auth_status) {
    if (auth_status != BLE_GAP_SEC_STATUS_SUCCESS) {
        g_pin_failures++;
        if (g_pin_failures >= 10) {
            g_pin_lockout_start = millis();
        }
    } else {
        g_pin_failures = 0;
        g_pin_lockout_start = 0;
    }
}

bool pairing_passkey_callback(uint16_t conn_handle, uint8_t const passkey[6], bool match_request) {
    return true;
}

void ble_sec_cb(uint16_t conn_handle) {
    g_pin_failures = 0;
    g_pin_lockout_start = 0;
}

}  // namespace
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
void loop() {
  nrf_wdt_reload_request_set(NRF_WDT, NRF_WDT_RR0);
  
  if (g_window_active && !Bluefruit.connected()) {
      if (millis() >= g_window_end_ms) {
          g_window_active = false;
          update_advertising();
      }
  }

  sd_app_evt_wait();

  // Process Serial Commands
  if (Serial.available()) {
      String cmd = Serial.readStringUntil('\n');
      cmd.trim();
      if (cmd.length() > 0) {
          process_management_command(cmd, true);
      }
  }
}

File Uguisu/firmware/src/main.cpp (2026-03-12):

#include <Arduino.h>

#include <bluefruit.h>

#include <Adafruit_LittleFS.h>
#include <InternalFileSystem.h>

#include "uguisu_config.h"
#include "led_effects.h"
#include <ImmoCommon.h>

using namespace Adafruit_LittleFS_Namespace;

namespace {

static constexpr const char* COUNTER_LOG_PATH = "/ug_ctr.log";
static constexpr const char* OLD_COUNTER_LOG_PATH = "/ug_ctr.old";

// Runtime key: from Whimbrel provisioned flash or compile-time default.
uint8_t g_psk[16];

immo::CounterStore g_store(COUNTER_LOG_PATH, OLD_COUNTER_LOG_PATH, immo::DEFAULT_COUNTER_LOG_MAX_BYTES);

// Callback for provisioning success
bool on_provision_success(const uint8_t key[16], uint32_t counter) {
  return immo::prov_write_and_verify(immo::DEFAULT_PROV_PATH, key, counter, g_store, g_psk);
}

static bool key_is_all_zeros() { return immo::is_key_blank(g_psk); }

static void load_provisioning() {
  immo::prov_load_key_or_zero(immo::DEFAULT_PROV_PATH, g_psk);
}

static TaskHandle_t g_prov_led_task = nullptr;
static void prov_led_task(void*) {
  while (true) { led::prov_pulse(); }
}

void start_advertising_once(uint16_t company_id, const uint8_t payload[immo::PAYLOAD_LEN]) {
  uint8_t msd[4 + immo::PAYLOAD_LEN];
  msd[0] = static_cast<uint8_t>(company_id & 0xFF);
  msd[1] = static_cast<uint8_t>((company_id >> 8) & 0xFF);
  msd[2] = static_cast<uint8_t>(immo::IMMOGEN_MAGIC & 0xFF);
  msd[3] = static_cast<uint8_t>((immo::IMMOGEN_MAGIC >> 8) & 0xFF);
  memcpy(&msd[4], payload, immo::PAYLOAD_LEN);

  Bluefruit.Advertising.stop();
  Bluefruit.Advertising.clearData();

  Bluefruit.Advertising.addFlags(BLE_GAP_ADV_FLAGS_LE_ONLY_GENERAL_DISC_MODE);
  Bluefruit.Advertising.addTxPower();
  Bluefruit.Advertising.addName();

  Bluefruit.Advertising.addData(BLE_GAP_AD_TYPE_MANUFACTURER_SPECIFIC_DATA, msd, sizeof(msd));

  Bluefruit.Advertising.setInterval((UGUISU_ADV_INTERVAL_MS * 8 + 4) / 5, (UGUISU_ADV_INTERVAL_MS * 8 + 4) / 5);
  Bluefruit.Advertising.restartOnDisconnect(false);
  Bluefruit.Advertising.start(0);
}

// Waits for button press, detects short/long press and triple clicks.
// Button is active LOW (INPUT_PULLUP). Returns immo::Command (Unlock, Lock, Window) or 0 on timeout.
static uint8_t wait_for_button_command(uint32_t timeout_ms) {
  if (digitalRead(UGUISU_PIN_BUTTON) != LOW) {
    // Pin already HIGH. We woke from sleep but user already released.
    return static_cast<uint8_t>(immo::Command::Unlock); 
  }

  const uint32_t deadline = millis() + timeout_ms;
  uint8_t click_count = 0;
  bool is_long_press = false;
  uint32_t last_release_time = millis();

  while (millis() < deadline) {
    if (digitalRead(UGUISU_PIN_BUTTON) == LOW) {
      uint32_t press_start = millis();
      bool released = false;
      
      while (millis() < deadline) {
        if (digitalRead(UGUISU_PIN_BUTTON) != LOW) {
           released = true;
           break;
        }
        if (millis() - press_start >= UGUISU_LONG_PRESS_MS) {
           is_long_press = true;
           break;
        }
        delay(10);
      }
      
      if (is_long_press) {
         return static_cast<uint8_t>(immo::Command::Lock);
      }
      
      if (released) {
        click_count++;
        last_release_time = millis();
        // Wait for next press within a short window for double/triple clicks
        bool next_press_detected = false;
        uint32_t multi_click_deadline = millis() + 400; // 400ms window for next click
        while (millis() < multi_click_deadline) {
           if (digitalRead(UGUISU_PIN_BUTTON) == LOW) {
              next_press_detected = true;
              break;
           }
           delay(10);
        }
        
        if (!next_press_detected) {
            break; // No more clicks within window
        }
      }
    } else {
        delay(10);
    }
  }

  if (click_count >= 3) {
      return static_cast<uint8_t>(immo::Command::Window);
  } else if (click_count > 0) {
      return static_cast<uint8_t>(immo::Command::Unlock);
  }

  return 0; // Timeout, no valid command
}

}  // namespace

void setup() {
  Serial.begin(115200);
  delay(50);

  led::init();
  pinMode(UGUISU_PIN_BUTTON, INPUT_PULLUP);

  if (!g_store.begin()) {
    Serial.println("InternalFS begin failed");
    led::error_loop(PIN_ERROR_LED);
  }

  load_provisioning();
  if (immo::prov_is_vbus_present()) {
    xTaskCreate(prov_led_task, "prov_led", 128, nullptr, 1, &g_prov_led_task);
  }
  immo::ensure_provisioned(immo::DEFAULT_PROV_TIMEOUT_MS, on_provision_success, load_provisioning, key_is_all_zeros);
  if (g_prov_led_task) {
    vTaskDelete(g_prov_led_task);
    g_prov_led_task = nullptr;
  }
  led::off();

  Serial.print("BOOTED: Uguisu-");
  Serial.println(__TIMESTAMP__);
  Serial.print("HWID: ");
  Serial.print(NRF_FICR->DEVICEID[0], HEX);
  Serial.println(NRF_FICR->DEVICEID[1], HEX);

  Bluefruit.begin();
  Bluefruit.setName("Uguisu");
  Bluefruit.setTxPower(0);

  // Wait for button: single press = Unlock, long press (>= 1s) = Lock, triple-press = Window
  const uint8_t cmd_val = wait_for_button_command(UGUISU_BUTTON_TIMEOUT_MS);
  if (cmd_val == 0) system_off();  // No press within timeout, sleep
  
  const immo::Command command = static_cast<immo::Command>(cmd_val);
  const uint8_t cmd_pin = (command == immo::Command::Lock) ? PIN_LED_R : PIN_LED_G;
  const bool low_bat = (readVbat_mv() < LED_LOWBAT_MV_THRESHOLD);

  const uint32_t last = g_store.loadLast();
  const uint32_t counter = last + 1;

  uint8_t nonce[immo::NONCE_LEN];
  immo::build_nonce(counter, nonce);

  uint8_t msg[immo::MSG_LEN];
  // Prefix byte packing: Prefix = (Slot_ID << 4). Uguisu must pack 0x00 (Slot 0).
  uint8_t prefix = (0 << 4);
  immo::build_msg(prefix, counter, command, msg);

  uint8_t ct[immo::MSG_LEN];
  uint8_t mic[immo::MIC_LEN];
  // 5 bytes AAD: prefix (1 byte) + counter (4 bytes)
  const bool ok = immo::ccm_auth_encrypt(g_psk, nonce, msg, sizeof(msg), 5, ct, mic);
  if (!ok) system_off();

  uint8_t payload[immo::PAYLOAD_LEN];
  memcpy(&payload[0], ct, sizeof(ct));
  memcpy(&payload[sizeof(ct)], mic, sizeof(mic));

  g_store.update(counter);
  start_advertising_once(MSD_COMPANY_ID, payload);
  const uint32_t adv_start = millis();

  if (low_bat) {
    led::flash_low_battery(cmd_pin);
  } else if (command == immo::Command::Window) {
    // Flash blue 3 times for Window command (or just use cmd_pin default, which would be green)
    // Actually, cmd_pin above defaults to green for Window. Let's make it a special sequence.
    for (int i = 0; i < 3; i++) {
        led::flash_once(PIN_LED_B, 50, 100, 50);
        delay(50);
    }
  } else {
    led::flash_once(cmd_pin, LED_FLASH_RISE_MS, LED_FLASH_HOLD_MS, LED_FLASH_FALL_MS);
  }

  const uint32_t elapsed = millis() - adv_start;
  if (elapsed < UGUISU_ADVERTISE_MS) {
    delay(UGUISU_ADVERTISE_MS - elapsed);
  }
  system_off();
}

void loop() {}

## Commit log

2026-03-06 Docs: Enrich README with hardware/power details
    Made-with: Cursor
2026-03-06 LED error loop, migrate gen_mic to ImmoCommon, update ImmoCommon submodule
    - Add LED blink error loop when InternalFS.begin() fails
    - Add PIN_ERROR_LED to config (default: XIAO red LED)
    - Migrate gen_mic.py to ImmoCommon submodule
    - Update PROTOCOL.md and tools/test_vectors/README.md
    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
    [main.cpp]
2026-03-06 Drop device_id: 9-byte payload, single counter, PROV:key:counter:checksum
    - Parse 9-byte MSD (counter, command, mic)
    - verify_payload / handle_valid_command use lastCounter(), update(counter)
    - on_provision_success(key, counter), seed receiver on provision
    - Update ImmoCommon submodule
    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
2026-03-06 Drop device_id: 9-byte payload, prov file key-only, PROV:key:counter:checksum
    - Remove UGUISU_DEVICE_ID and g_device_id
    - Prov file: magic+key (20 bytes) only
    - Build 9-byte payload with build_nonce(counter), build_msg(counter, command)
    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
2026-03-07 Update README BOM ref numbers to match production BOM
    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
2026-03-07 Ignore production artifacts in git
    Added the production folder to .gitignore.
    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
    [Guillemot_bom.csv]
2026-03-07 docs: sort BOM sensibly (ICs, power, discrete, passives)
    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
2026-03-07 docs: annotate extended parts in BOM
    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
2026-03-07 Add BOM matched parts doc, update README
    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
2026-03-07 Stop tracking production folder; add production/ to .gitignore
    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
    [Uguisu_bom.csv, Uguisu_designators.csv, Uguisu_positions.csv]
2026-03-08 Remove fix_readme_cost.py, stop tracking production folder (in .gitignore)
    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
    [Guillemot_bom.csv, Guillemot_designators.csv, Guillemot_positions.csv]
2026-03-09 refactor: unify PSK storage, add utils, fix counter and dead code
    - prov_write_and_verify() + prov_load_key() in immo_provisioning: normalized
    PSK flash format (PROV_MAGIC 0x564F5250 + key) shared by both devices,
    eliminating per-device on_provision_success boilerplate
    - New immo_util module: is_key_blank() and led_error_loop(pin) extracted from
    duplicate copies in guillemot/main.cpp and uguisu/main.cpp
    - immo_storage: CounterStore::load() now tracks max counter seen, not last,
    closing theoretical replay window from flash corruption
    - immo_crypto: delete dead le16_write() (never called, wrong endianness)
    - ImmoCommon.h: include immo_util.h
    - README: document new provisioning helpers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
2026-03-09 refactor: use ImmoCommon prov/util helpers, normalize PSK storage path
    - on_provision_success: delegate to immo::prov_write_and_verify() — formats
    PSK as PROV_MAGIC + key (20B), removes redundant InternalFS.remove calls
    - load_psk_from_storage: delegate to immo::prov_load_key()
    - PSK storage path changed from /psk.bin to /prov.bin (re-provisioning required)
    - key_is_all_zeros: thin wrapper over immo::is_key_blank()
    - led_error_loop: replaced with immo::led_error_loop(PIN_ERROR_LED)
    - bump ImmoCommon submodule to d25e3d9
    [main.cpp]
2026-03-09 refactor: rename config header to guillemot_nrf52840.h, two-tone buzzer, add buzzer tuner
    - Rename guillemot_config.example.h → guillemot_nrf52840.h to match Uguisu
    naming convention (board-specific defaults clearly identified)
    - Add __has_include("guillemot_config_local.h") override guard to guillemot_config.h
    - Move latch_set_pulse() and latch_reset_pulse() from main.cpp into
    guillemot_nrf52840.h as inline board-specific hardware functions
    - Replace single BUZZER_HZ/UNLOCK_MS/LOCK_MS with two-tone defines:
    BUZZER_LOW_HZ=2637, BUZZER_HIGH_HZ=3952, BUZZER_LOW/HIGH_MS=130
    - Update buzzer_tone_ms() to accept hz param; unlock plays low→high,
    lock plays high→low
    - Add tools/buzzer_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
    [guillemot_nrf52840.h, main.cpp]
2026-03-09 tune: set BLE timing to 500/20 ms scan, 600/20 ms advertise
    Guillemot: SCAN_INTERVAL_MS 2000→500, SCAN_WINDOW_MS 20→20 (no change).
    Uguisu: UGUISU_ADVERTISE_MS 2000→600, UGUISU_ADV_INTERVAL_MS 100→20.
    20 ms is the minimum legacy advertising interval on S140 SoftDevice.
    Also adds ble_timing_simulator.html with updated defaults matching firmware.
2026-03-09 feat(simulator): link-intervals toggle + phase slider sync on press
    - Add toggle to lock scan interval ↔ adv duration and scan window ↔
    packet interval; bidirectional, clamped to each slider's range
    - Sync phase offset slider position to the random phase used on
    'Press Fob Button' so the strip highlight matches the timeline
2026-03-09 docs: Uguisu README updates, BLE power analysis, log cleanup
    - Uguisu README: updates (duty cycle, power refs)
    - Add logs/15-BLE_POWER_ANALYSIS_AND_DOCUMENTATION_DISCREPANCY.md
    - Remove logs: BLE_SCAN_DUTY_CYCLE, FULL_CODEBASE_DOCUMENTATION,
    REVIEW_FIXES_TECHNICAL_WRITEUP
    - Add logs/ai_studio_code(13).html
    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
2026-03-09 Reorganize: move KiCad to hardware/, remove tools, consolidate .gitignore
    - Move KiCad files to Guillemot/hardware/ and Uguisu/hardware/
    - Remove Guillemot/tools and Uguisu/tools
    - Merge all .gitignore rules into root .gitignore
    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
    [Guillemot.kicad_pcb, Guillemot.kicad_sch, Uguisu.kicad_pcb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]
2026-03-10 docs: standardize log date format, document latch pull-downs, add MCU reset analysis
    - Guillemot README: BOM split for R1/R2 latch pull-downs, design note on WDT reset safety
    - logs: standardize all to *Date: YYYY-MM-DD HH:mm*
    - Add logs/26-MCU_RESET_LATCH_STABILITY.md
    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
2026-03-11 docs: add finalized Pipit master architecture (log 33)
    Comprehensive single-source-of-truth superseding logs 30-32. Covers
    BLE proximity architecture with iBeacon iOS optimization, stateful
    beaconing UUIDs, GATT service/characteristic UUIDs, 14-byte AES-CCM
    payload structure, 6-digit PIN + Argon2id (256MB) encrypted QR
    provisioning, serial-only management commands, and full codebase
    modification checklist across ImmoCommon, Guillemot, Uguisu, and
    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
2026-03-11 docs: update logs 30-32 with slot naming, RENAME command, and migration flows
    Align earlier Pipit docs with finalized architecture in log 33:
    - Log 30: add device name to QR/PROV format, expand BLE key management
    to include RENAME and lost-phone recovery flow
    - Log 31: add optional name field to PROV command, add RENAME command
    to serial protocol table, clarify SLOTS? returns JSON with names
    - Log 32: add Section 6 covering migration and recovery flows to avoid
    leapfrog counter desyncs when transferring keys between phones
2026-03-11 docs(pipit): update master architecture with dynamic beaconing and edge case handling
2026-03-11 feat: implement Pipit architecture (4-slot keys, dual BLE roles, SMP)
2026-03-12 refactor(firmware): update multi-slot storage and provisioning flow
    - Updated `CounterStore` and `KeySlot` arrays to dynamically support 4 slots instead of a legacy single-slot monolithic approach.
    - Implemented `verify_payload` slot-id extraction and bound it to `g_session_slot` for BLE command gating.
    - Refactored `process_management_command` to support `SETPIN`, `RESETLOCK`, `PROV` (with URL decoding), `RENAME`, `SLOTS?`, `REVOKE`, and `RECOVER`.
    - Updated `Uguisu` button debouncer to detect triple clicks and emit `immo::Command::Window` payload.
    - Added `B99F8D...` Window UUID for dynamic beaconing based on `g_window_active` timer.
    - Refined doc logs with `PROVISIONING_CHECKSUM_REMOVAL.m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
    [main.cpp]
